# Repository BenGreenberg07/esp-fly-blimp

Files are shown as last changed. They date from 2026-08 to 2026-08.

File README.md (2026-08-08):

# ESP-FLY Autonomous Blimp

Converting a tiny ESP32-S3 quadcopter into an **autonomous helium blimp** that flies
itself to motion-capture waypoints — hand-flyable and self-flying from a live browser
panel, commanded over a custom **ESP-NOW** radio link so the laptop never has to leave
the lab Wi-Fi.

This repo contains the full stack: the drone firmware, the USB↔radio bridge firmware,
the real-time 3D control/tuning panels, and the printable gondola.

```
OptiTrack ──Wi-Fi──▶ Laptop ──USB──▶ XIAO ESP32-C6 ──ESP-NOW──▶ ESP32-S3 (blimp)
 (pose stream)      (control panel)   (radio bridge)            (guidance + mixing)
```

The laptop stays on the mocap network the whole time — control rides a **separate
ESP-NOW radio path**, solving the "one Wi-Fi radio can't be on two networks at once"
problem.

---

# Getting started

## 1. Getting the code

Clone it or download it — either works. You only need the files on your computer — there is nothing to install
globally and no build step for the ground station.

```bash
git clone https://github.com/BenGreenberg07/esp-fly-blimp.git
cd esp-fly-blimp
```

No git? Click the green **Code ▾ → Download ZIP** button on GitHub and unzip it. Same
thing.

## 2. Minimum files required

**To FLY (ground station only) — this is most people, most of the time:**

| You need | Why |
|---|---|
| `run.py` | the launcher you press ▶ on |
| `config.json` | your Motive IP + rigid-body ID — **you must edit this** |
| `requirements.txt` | the three Python packages |
| `control/` | the panel server + the browser pages + the saved tuning |
| `optitrack_natnet/` | the mocap client (includes a macOS multicast fix) |

That's it. You can ignore `esp-drone/`, `espnow_bridge/`, `hardware/`, `docs/`, and
`archive/` entirely unless you are building or reflashing a blimp.

**To BUILD or REFLASH a blimp**, you also need `esp-drone/` (drone firmware),
`espnow_bridge/` (bridge firmware), and `hardware/` (the printable gondola). See
**[Building a blimp from scratch](#building-a-blimp-from-scratch)** below.

## 3. Install and configure

```bash
pip install -r requirements.txt
```

Then edit **`config.json`**:

```json
{ "motive_ip": "192.168.0.4", "body_id": 531, "up": "Z" }
```

| field | meaning |
|---|---|
| `motive_ip` | IP of the OptiTrack/Motive PC streaming NatNet |
| `body_id` | the blimp's Rigid Body **Streaming ID** in Motive |
| `up` | up axis, `"Z"` or `"Y"` (also togglable live in the panel) |

## 4. Run it

Open the folder in VS Code → **Run and Debug** (▶ in the left bar) → pick a panel and
press the green ▶. Or from a terminal:

```bash
python run.py --mode auto
```

The panel opens in your browser. Press **ARM** to connect the USB bridge, then fly.

> **Have running before you press ARM:** the blimp powered on, the ESP32-C6 bridge
> plugged into your computer, and your computer on the same network as the Motive PC.

**Nothing here needs a reflash.** Every gain is a live slider; the drone runs its own
guidance and the panel just streams pose, commands, and tuning to it.

## 5. What each script does

There are two scripts in this repo. The first is the one used for flying:

| Script | When you use it |
|---|---|
| **`run.py`** | **Every time you fly.** Starts the ground station: a small local web server plus the browser page you actually click on. |
| **`flash.py`** | **Rarely.** Only to put new firmware on a board. Not needed to fly, and not needed to change any gain. |

The word "panel" just means that browser page — the thing with the live 3D view, the
buttons, and the sliders. `--mode` picks which page you get (`auto`, `manual`, `wander`,
`swing`); they're all served by the same program.

**The controller is separate from the panel, and it isn't running on your laptop.** The
control math — steering toward the target, holding altitude — lives in the drone's own
firmware (`blimp_guidance.c`). Your laptop only tells it *where it is* and *where to go*,
and passes along gain changes when you move a slider. That's why nothing needs reflashing
when you tune, and why the path drawn on screen is a picture of what the drone is doing
rather than the thing steering it.

(The one exception is the experimental `swing` mode, where the controller does run on the
laptop — explained in [Next steps](#next-steps--the-s-blimp-4-motor-airframe).)

---

# Returning to a point after a hand push

Push the blimp by hand and it curves back to the point it was assigned. This needs no
special mode — it is a direct consequence of the constant-cruise pursuit controller.

1. `python run.py --mode auto`, then **ARM**.
2. Click **⋯ Path** (the path mode button in the *Auto path shape* card).
3. **Click once** in the 2D view, on the spot you want it to live. That single click is
   the whole configuration — one waypoint.
4. Leave **Loop** on. Press **▶ GO**.

It climbs to the target altitude, flies to your point, and then keeps circling it at its
minimum turn radius. Push it across the room and the steering carrot is still that one
point, so it banks around and comes back on a curve. Release it and it re-converges.

**It orbits rather than parks.** The forward motors run at constant cruise and can't
reverse, so the craft cannot brake to a stop — expect a slow circle around the point,
not a hover on it. If you want it to genuinely stop, sit still, and wait to be pushed,
use the **wander** panel instead (`python run.py --mode wander`): it cuts cruise on
arrival so the blimp coasts to a halt and is safe to grab, flashes the LED, waits for
your push, then flies to the next point.

### Suggested improvement: replace the constant cruise

The clearest place to take this further is the constant-cruise assumption itself. The
controller currently holds forward power fixed and only steers, which is what makes it
smooth on loops — but it is also the reason it can only orbit a point instead of settling
on it.

Worth building and testing: **a speed controller that modulates forward thrust by distance
to the target**, so the craft eases off as it approaches and coasts to a near-stop on the
point rather than circling it. Some useful starting material is already here:

- The **wander** mode already does a simple version — an approach taper that rolls cruise
  off linearly over the last metre or two, plus a `fwdMaxN = 0` "park" state on arrival.
  Generalising that into the main auto mode is the obvious first experiment.
- `control/flight_logs/plant_final_*.json` is an identified model of the vehicle's
  dynamics, so a stopping distance can be predicted rather than guessed. The craft coasts
  a long way: forward drag has a time constant of roughly 5–7 seconds.

Two things to expect. Because the motors cannot reverse, the approach has to be planned
early — by the time it is close, cutting thrust is the only remaining control. And below
roughly 0.15 m/s the constant sideways drift becomes comparable to the forward speed, so
creeping in slowly tracks *worse*, not better. A decelerating approach that still arrives
with some speed is likely the practical target. The complete fix is hardware: H-bridge
drivers giving the motors reverse thrust, and therefore actual braking — see
[Future additions](#future-additions).

---

# The four panels

All of them are the same server (`control/panel_server.py`) started in a different mode.
See **[control/README.md](control/README.md)** for the full detail.

### ⭐ Auto — `python run.py --mode auto` (port 8601)
The day-to-day tool. Streams your live mocap pose to the drone's **on-board guidance**
(firmware `blimp_guidance.c`) — pure-pursuit steering with a lookahead carrot plus an
altitude PID. Fly a drawn **path**, a **circle**, or a manual X/Y **point**.
Every gain is a live slider. Also has hand-fly, gamepad control, sys-ID test buttons, and
per-run CSV/PNG logging.

### Manual — `python run.py --mode manual` (port 8611)
Pure hand-fly, no autonomy: `W/S` forward, `A/D` turn, `Q/E` up/down, `Space` = kill,
plus hover-assist, trim, and per-direction power sliders. The simplest option for a first
flight, a bridge check, or a motor sanity check.

**Gamepad supported** (Auto mode has it too). An Xbox controller — or any USB/Bluetooth
pad the browser recognises — gives you *proportional* control instead of on/off keys:
**RT** = forward throttle, **right stick X** = turn, **left stick Y** = up/down,
**B** = KILL. The keyboard keeps working alongside it, and if the pad is unplugged or the
tab loses focus the panel falls back to the keys within a fraction of a second, so a
forgotten pad can never hold the motors on. Browsers only expose a gamepad after you
press a button on it, so "no pad" until first input is expected.

### Wander — `python run.py --mode wander` (port 8613)
Flies to a point (random within a box, or a list you click), **parks and coasts to a
stop**, flashes the drone LED to say "safe to touch", waits for a hand push, then picks
the next point. The push is detected from mocap speed, so no extra sensor.

### Swing — `python run.py --mode swing` (port 8620) — **untested**
The new 4-motor S-blimp airframe with an SE(3) Mellinger controller. Built and
bench-verified but **never flown**. See [Next steps](#next-steps--the-s-blimp-4-motor-airframe).

---

# Building a blimp from scratch

My custom build guide video: [https://youtu.be/fltrr_Snbas](url)

Start to finish, in the order you should actually do it.

### Step 1 — Parts

| Part | Notes |
|---|---|
| Seeed **XIAO ESP32-S3** micro-drone (ESP-Drone) | the flight board — 4 brushed motor channels |
| A second **XIAO ESP32-S3** (or ESP32-C6) | the USB↔ESP-NOW bridge that plugs into your laptop |
| 4× brushed coreless motors + props | 2 forward, 1 up, 1 down (see the mixer below) |
| Helium envelope (mylar) | must lift the gondola + battery with a little margin |
| 1S LiPo | small — weight is everything |
| Printed gondola | `hardware/` — see step 2 |
| OptiTrack / Motive + markers | for anything autonomous |

### Step 2 — Print the gondola

In **`hardware/`**:

| File | What it is |
|---|---|
| `gondola-frame-v5.stl` | the flying gondola — print this one |
| `balloon-mount-v2.stl` | the pad that tapes to the envelope |
| `s-blimp-frame-test2.stl` | the 4-motor S-blimp frame (next-gen, see below) |
| `blimp-gondola-mount.f3d`, `esp-blimp-frame.f3d` | Fusion 360 sources, if you want to change dimensions |

**Two geometry choices that matter more than any gain:**
- **Spread the two forward motors as wide as you can.** Yaw torque scales with their
  separation, and turn authority is the single biggest limit on this vehicle.
- **Mount the gondola centred under the envelope.** An off-centre mount gives a constant
  sideways drift that no controller can remove — this was measured and confirmed, and it
  is the dominant tracking error at low speed.

### Step 3 — Wire the motors

Motor roles are set in firmware, not by which wire you solder where, so you can fix a
mistake in software. The default map (`power_distribution_stock.c`):

```
M1 = DOWN      M2 = forward-LEFT      M3 = forward-RIGHT      M4 = UP
```

Verify it before you fly: `python control/check_link.py --spin` spins each channel
briefly at low power (**props off**) so you can see which motor is which. If they don't
match, edit the `MOTOR_FWD_LEFT / MOTOR_FWD_RIGHT / MOTOR_UP / MOTOR_DOWN` defines and
reflash — don't resolder.

### Step 4 — Flash the drone (ESP32-S3)

Install **ESP-IDF v5.0.x**, then:

```bash
cd esp-drone
idf.py set-target esp32s3      # FIRST TIME ONLY — the committed sdkconfig needs this
idf.py build
idf.py -p /dev/cu.usbmodemXXXX flash
```

Or let the helper script do all of that for you, on any OS:

```bash
python flash.py drone
```

It finds the port, sets up ESP-IDF if it isn't already on your PATH, and builds and
flashes in one step.

> **If flashing fails** with *"No serial data received"* or *"Invalid head of packet"*:
> the S3 talks over its internal USB-Serial-JTAG. Add `--before usb_reset`, or unplug the
> LiPo and replug the USB cable, then retry immediately. The chip is never damaged by a
> failed connect — esptool fails before it writes anything.

### Step 5 — Flash the bridge (ESP32-S3 or C6)

The bridge can be **either a XIAO ESP32-S3 or a XIAO ESP32-C6** — the same sketch builds
for both (the C6-only antenna switch is compiled out on an S3). An S3 is the easy choice
since it's the same board as the drone:

```bash
python flash.py bridge            # XIAO ESP32-S3 (default)
python flash.py bridge --board c6 # XIAO ESP32-C6
```

Needs `arduino-cli` with the Arduino **esp32 core 3.x**. The Arduino IDE works too — open
`espnow_bridge/espnow_bridge.ino` and pick board `XIAO_ESP32S3` or `XIAO_ESP32C6`.

> If you use `arduino-cli` by hand, note that `upload` on its own re-flashes the *last
> compiled* binary — always `compile --upload` together or you'll flash a stale sketch.
> (`flash.py` does this correctly for you.)

> **Using a C6?** Check whether your board has a u.FL external-antenna connector. The
> sketch enables the external antenna, so the physical antenna must be attached — with
> the switch set and no antenna fitted, range is *worse* than stock.

Your USB adapter will usually only show **one** port at a time, so flash the two boards
one after the other, not together.

### Step 6 — Bind the drone to its bridge

There is **no MAC address to type in**. Pairing is a 4-byte tag called `FRAME_MAGIC` that
both ends stamp on every packet and reject if it's missing — that's what stops your blimp
from being flown by the other ESP-NOW traffic in the room (which was a real bug: foreign
frames were being parsed as gain updates and crashing the drone).

A bridge and a drone are **bound when their `FRAME_MAGIC` values match**:

| File | Where |
|---|---|
| `espnow_bridge/espnow_bridge.ino` | search for `FRAME_MAGIC` (~line 42) |
| `esp-drone/components/espnow_control/espnow_control.c` | search for `FRAME_MAGIC` (~line 46) |

Out of the box both are `{0xB1, 0x12, 0x9F, 0x5A}` and one drone works with no changes.

**Flying a second blimp in the same room:** give triplet #2 (its own laptop + bridge +
drone) a different `FRAME_MAGIC` — any 4 bytes — set **identically in both files**, then
reflash **both** of its boards. Leave triplet #1 and `TELEM_MAGIC` alone, and keep
everyone on channel 1. Full write-up: [espnow_bridge/README.md](espnow_bridge/README.md).

### Step 7 — First flight

1. Fill the envelope so it is **very slightly negatively buoyant** — it should sink
   slowly when you let go. Trim with tape.
2. Plug the C6 into the laptop, power the blimp.
3. `python control/check_link.py` — confirms the drone is actually replying over
   ESP-NOW (motor telemetry, not just an open serial port). Do this before blaming the
   panel.
4. `python run.py --mode manual` → **ARM** → hand-fly it. Get up/down and turning
   working, and set the power sliders where it feels controllable.
5. Only then go autonomous: `python run.py --mode auto`, create your rigid body in
   Motive, check the tracking pill goes green, and try the
   [come-back-when-pushed](#make-it-come-back-when-you-push-it) recipe above.

**If it turns the wrong way**, hit **⟳ Flip turn direction** in the panel (it flips the
sign of `turnMaxPwm`). Don't rewire.

---

# Tuning

Every gain — manual powers/trims and autonomous pursuit/hover gains — is a live slider.
Values ride the ESP-NOW link and update the controller in RAM instantly, with no reflash.
The panels are **self-contained** (pure-canvas 2D/3D, no CDNs) so they run on a
locked-down lab network, and they save automatically.

`control/mocap_config.json` ships with **the tuning currently flying on my blimp**, so a
fresh clone starts from known-good numbers instead of defaults:

| | |
|---|---|
| `fwdMaxN` 0.18 | constant forward cruise — the main speed/turn-radius trade |
| `kpHead` 2.65, `kdHead` 0.037 | pursuit steering PD (kd is the anti-overshoot term) |
| `turnCap` 0.9, `turnBoost` 0.35 | turn authority and how symmetric the differential is |
| `driftK` 1.3 | crab into the sideways drift |
| `zff` 19000, `vertMaxPwm` 28000 | buoyancy feedforward and its output ceiling |

**Radius scales with speed.** Flying wider circles than you drew is almost always
`fwdMaxN` being too high, not a steering gain. Slowing down is the strongest lever.

# Repo layout

```
run.py                  ▶ the launcher (VS Code ▶, or `python run.py --mode auto`)
config.json             your Motive IP + rigid-body IDs — EDIT THIS
requirements.txt        Python deps (numpy, matplotlib, pyserial)

control/                the ground station — everything you need to fly
  ├─ panel_server.py          the server behind all four modes
  ├─ auto_panel.html          Auto page (2D/3D mocap view, path drawing, live tuning)
  ├─ manual_panel.html        Manual hand-fly page
  ├─ wander_panel.html        Wander page (park → wait for a push → next point)
  ├─ swing_panel.html         Swing / S-blimp page (untested)
  ├─ swing_panel_server.py    Swing server — separate controller and motor layout
  ├─ mellinger_core.py        SE(3) Mellinger controller + the geometry-driven mixer
  ├─ swing_trajectory.py      trajectory generator for the swing build
  ├─ mocap_config.json        the tuning that is currently flying
  ├─ check_link.py            terminal-only link + motor test (run this first)
  └─ flight_logs/plant_final_*.json    identified dynamics model

hardware/               printable gondola (STL) + Fusion 360 sources + the S-blimp photo
esp-drone/              on-board drone firmware (ESP-IDF, ESP-Drone derivative)
espnow_bridge/          XIAO ESP32-C6 USB↔ESP-NOW bridge (Arduino) + pairing guide
optitrack_natnet/       OptiTrack NatNet client (incl. a macOS multicast fix)
docs/                   design notes and write-ups
archive/                earlier / superseded tools kept for history
```

Inherited the physical hardware rather than building your own? The specific IDs,
addresses, and quirks of the blimp I actually flew are in
[docs/THIS_EXACT_BLIMP.md](docs/THIS_EXACT_BLIMP.md).

### On-board firmware (custom components)
Built on Espressif's [ESP-Drone](https://github.com/espressif/esp-drone) (a Crazyflie
port). The custom work:
- `.../blimp_guidance.c` — the on-board guidance controller (pursuit + carrot + altitude
  PID + soft-start + spin abort)
- `.../power_distribution_stock.c` — blimp motor mixer (constant-forward + differential
  turn, vertical sign/dead-band) and the swing-build 4-motor branch
- `.../stabilizer.c`, `.../system.c` — blimp flight mode + radio-link selection
- `components/espnow_control/` — ESP-NOW receiver (manual + pose + gains frames, magic-tag
  filtering, link-loss failsafe) and the motor-telemetry return path
- `components/ble_control/` — BLE control link (parked)

---

# Next steps — the S-blimp 4-motor airframe

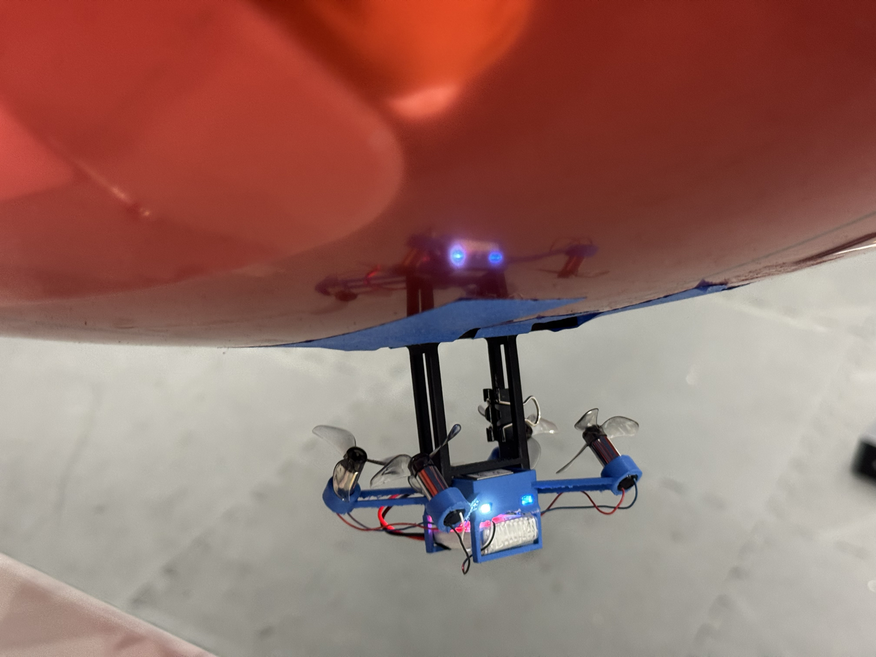
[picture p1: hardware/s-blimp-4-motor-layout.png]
The S-blimp gondola: four motors on an X-frame, canted ~45°


The next airframe replaces "2 forward + 1 up + 1 down" with **four motors on an X-frame,
all pointing roughly upward, canted about 45°** (photo above; frame is
`hardware/s-blimp-frame-test2.stl`).

**Motivation.** The current blimp's problems all trace back to one thing: the only
horizontal actuator is a pair of unidirectional forward motors, so it can't brake, can't
rotate in place, and drifts sideways through every turn. Four canted motors change the
actuation entirely — vertical thrust and yaw come out directly, and horizontal motion
comes from **tilting the envelope so the gondola's pendulum swings and the tilted lift
vector pulls it along** (hence "swing blimp").

**What already exists in this repo (built, bench-tested, `--mode swing`):**
- `control/mellinger_core.py` — a port of the Bitcraze **SE(3) Mellinger** controller,
  running host-side because it needs the full attitude quaternion every tick and the
  pose frame only carries position + yaw.
- A **geometry-driven mixer**: per-motor position + thrust axis → a 4×4 allocation
  matrix, solved by damped least-squares because the matrix is **singular by design**.
  Three switchable cant layouts (`lateral`, `foreaft`, `tangential`); unachievable force
  is routed into a moment, which is what makes the swing happen.
- Firmware support behind `#define BLIMP_SWING` (default 0 — nothing changes until you
  set it). In this build the drone is a **dumb 4-channel motor amplifier** and the wire
  format is the unchanged `0xA5` frame, so **only the drone reflashes, not the bridge**.
- A panel with props-off per-motor bench buttons and a motor-map editor, so you map
  channels to arms by clicking rather than resoldering.

**Remaining work:**
1. `python flash.py swing` (drone only; `python flash.py drone` puts the old blimp back).
2. Props off — bench-test M1..M4 and set the motor map from what actually spins.
3. Confirm the real cant matches a layout — watch which allocation row reads zero.
4. Raise `hover` until it floats, then ENGAGE with the target at its current position.
5. **Start the rate-D gains (`kw_*`, `kd_omega_rp`) well below the reference values** —
   they assume a 500 Hz IMU, but here body rates come from 25 Hz mocap.

---

# Future additions

### PCB with an integrated ESP32
Today the flight board is a XIAO module soldered onto a carrier — the between-board
joints are the most fragile thing on the vehicle and they add height and weight. The plan
is a **custom PCB with the ESP32-S3 native on the board**: no module, no inter-chip
soldering, one part to place.

### H-bridge motor drivers for reverse thrust
The single biggest limitation of the whole design is that the brushed motors are driven
by one low-side MOSFET each, so they only spin one way. Adding **H-bridge drivers
(e.g. DRV8833)** would let the forward motors reverse, which buys:
- **turning in place** — oppose the two forward motors instead of arcing
- **braking**, so it can actually stop on a point instead of orbiting it
- much tighter path tracking, since the min-turn-radius floor largely goes away

This needs signed PWM in the mixer and a firmware reflash once the hardware is wired.

**PCB design files and work-in-progress:**
[Google Drive folder](https://drive.google.com/drive/folders/18QSSe5u8A_p2iix2rqLfaRU-QODWJp0w)

---

# Wi-Fi mode (fallback, and how to revert)

ESP-NOW is the primary control link, but the drone **also brings up its own Wi-Fi access
point**, so Wi-Fi control is available at any time with no reflashing.

| Setting | Value |
|---|---|
| SSID | `ESP-DRONE_xxxxxxxxxxxx` |
| Password | `12345678` |
| Control link (CRTP over UDP) | `udp://192.168.43.42:2390` |

There's no bundled panel for this path — drive it with `cflib`'s `cfclient` or your own
script. Older keyboard-teleop clients (`drive_blimp*.py`) are in `archive/`.

**To make Wi-Fi the *only* radio**, edit
`esp-drone/components/core/crazyflie/modules/src/system.c`:

```c
#define ESPNOW_CONTROL_ENABLED 0   // 1 = ESP-NOW (default), 0 = Wi-Fi only
#define BLE_CONTROL_ENABLED    0   // (BLE link, normally off)
```

then rebuild and flash.

---

# Troubleshooting

**If the panel will not connect, or nothing moves,** run the terminal-only check first — it opens
the bridge, confirms the drone is really replying over ESP-NOW, and can spin each motor:

```bash
python control/check_link.py                       # test the link only (no spin)
python control/check_link.py --spin                # + spin each channel briefly, props OFF
python control/check_link.py --bridge-port COM5    # if auto-detect picks the wrong port
```

| Symptom | Cause |
|---|---|
| Tracking pill never goes green | laptop isn't on the mocap network, or the wrong `body_id` |
| Flies wider circles than drawn | `fwdMaxN` too high — slow it down |
| Turns the wrong way | **⟳ Flip turn direction** in the panel |
| Sinks during flight | buoyancy or battery sag, not gains — check `zff` isn't above `vertMaxPwm` |
| Random jitter / drone reboots ~3 s in | another ESP-NOW device in the room; check `FRAME_MAGIC` matches on both your boards |

---

# License
The `esp-drone/` firmware is a derivative of Espressif ESP-Drone and remains **GPL-3.0**
(original license headers retained). The host-side tools, panels, and hardware are
original work by the author.

---

*Built by Ben Greenberg. An exercise in re-purposing a flight controller, control design
around a hard actuation constraint, embedded radio links, and real-time tooling.*

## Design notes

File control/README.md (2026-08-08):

# control/ — the ground station

Everything that runs on your laptop. Start it from the repo root with
`python run.py --mode <auto|manual|wander|swing>`. Run these files directly only when
debugging.

## Contents

| File | What it does |
|---|---|
| `panel_server.py` | **The server.** Reads mocap (NatNet), streams pose + commands + gains to the drone over the USB↔ESP-NOW bridge, serves the browser page, and logs every run. One file, three pages. |
| `auto_panel.html` | The **Auto** page — 2D/3D mocap view, path drawing, live gain sliders, hand-fly, gamepad, sys-ID tests. |
| `manual_panel.html` | The **Manual** page — hand-fly only. |
| `wander_panel.html` | The **Wander** page — fly to a point, park, wait for a push, repeat. |
| `mocap_config.json` | Saved tuning (the numbers currently flying). Written automatically whenever you move a slider. |
| `check_link.py` | Terminal-only link + motor test. **Run this first** when something won't connect. |
| `flight_logs/` | Per-run `run_<timestamp>.csv` + plots. `plant_final_20260727.json` is the identified dynamics model and is kept in git. |

**Swing / S-blimp build (separate, untested):**

| File | What it does |
|---|---|
| `swing_panel_server.py` | Standalone server for the 4-motor airframe (port 8620). Own NatNet reader, own control thread. |
| `swing_panel.html` | Its page — per-motor bench buttons, motor-map editor, live allocation matrix. |
| `mellinger_core.py` | SE(3) Mellinger controller port + the geometry-driven damped-least-squares mixer. |
| `swing_trajectory.py` | Trajectory generator for that build. |

## Control flow

```
Motive ──NatNet──▶ panel_server.py ──USB serial──▶ C6 bridge ──ESP-NOW──▶ drone
```

Frames going down the wire are told apart by a 4-byte magic tag plus their length:

| Frame | Payload | Meaning |
|---|---|---|
| `0xA5` | 16 B | manual setpoint (roll/pitch/yaw/thrust) — also what the swing build reuses as 4 motor duties |
| `0xA6` | 32 B | mocap pose + goal — engages the drone's on-board guidance |
| `0xA7` | 84 B | the live gains — sent whenever you move a slider |
| `0xB7` | 16 B | **coming back:** motor telemetry (mL, mR, mUp, mDown), logged into every run CSV |

**The drone does the flying.** In auto mode the panel only supplies pose and tuning; the
pursuit + altitude loops run in firmware (`blimp_guidance.c`). That's why no gain change
ever needs a reflash, and why the path drawn on screen is a *mirror* of the on-board math
rather than the source of it.

## Safety behaviour

- **Browser watchdog** — if the page stops polling for 1.5 s the server stops streaming,
  and the drone's own stale-pose failsafe cuts the motors.
- **KILL** is always visible and always immediate.
- **Link-loss failsafe** — if the bridge goes silent the drone zeroes the motors within
  250 ms rather than flying away.
- **Soft-start** ramps the motors over ~0.7 s so engaging can't brown out the battery.

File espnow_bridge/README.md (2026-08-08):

# ESP-NOW bridge (XIAO ESP32-C6 or XIAO ESP32-S3)

USB↔ESP-NOW relay. The Mac talks to this board over USB serial; the board
rebroadcasts to the blimp over ESP-NOW. This keeps the Mac's Wi-Fi free for the
mocap (OptiTrack/NatNet) network — no router, no Wi-Fi join, no pairing UI.

**Same sketch, same file (`espnow_bridge.ino`), either board.** The bridge can
be a Seeed XIAO ESP32-**C6** or a Seeed XIAO ESP32-**S3** — pick whichever you
have. The only difference is which `arduino-cli --fqbn` you flash with (see
"Flashing" below); nothing in the sketch needs editing either way. (The one
board-specific bit, the C6's RF-antenna-switch pins, is already handled for
you at compile time via `#if defined(CONFIG_IDF_TARGET_ESP32C6)` — an S3
bridge just skips that block and uses its fixed onboard antenna.)

```
Mac (panel) --USB serial--> XIAO ESP32-C6 or -S3 --ESP-NOW--> ESP32-S3 (blimp)
            <--0xB7 telem-- (bridge relays)      <----------- (motor telemetry)
```

---

## "Where do I put the MAC address?"

**Nowhere — and that's deliberate. There is no MAC address to configure.**

The bridge **broadcasts** to `FF:FF:FF:FF:FF:FF`, so it does not need to know the
drone's MAC, and the drone does not need to know the bridge's:

```c
// espnow_bridge.ino
static uint8_t BCAST[6] = {0xFF, 0xFF, 0xFF, 0xFF, 0xFF, 0xFF};
```

If you flashed a *new* drone board, or swapped the C6 for another bridge, **you
do not have to change anything.** They will link up as long as the three things
below match.

> **Why broadcast instead of unicast?** An earlier version unicast to the drone's
> STA MAC. That broke once the drone started running ESP-NOW
> on top of its Wi-Fi SoftAP, because its *active* interface MAC became the **AP**
> MAC, not the STA MAC — so every send failed with `ESP_ERR_ESPNOW_IF (0x306c)`,
> silently (receive still worked, so it looked fine). Broadcast is delivered
> regardless of which interface is up, so it just works. Don't "fix" this back to
> unicast unless you have a reason.

---

## What actually pairs the two boards

Three things must match. If the link is dead, check them in this order.

### 1. Wi-Fi channel — must be the same on both

| Side | File | Setting |
|---|---|---|
| Bridge (C6 or S3) | `espnow_bridge/espnow_bridge.ino` | `static const uint8_t ESPNOW_CHANNEL = 1;` |
| Drone (S3) | `esp-drone/components/espnow_control/espnow_control.c` | pinned by the SoftAP, `WIFI_CH = 1` |

The drone runs ESP-NOW *on top of* its SoftAP, which pins the channel. (This also
fixed an old bug where `esp_wifi_set_channel()` wouldn't stick in pure-STA mode.)

### 2. `FRAME_MAGIC` — the real "pairing key"

This is what actually keeps *your* blimp listening to *your* bridge:

```c
// MUST be identical in BOTH files:
//   espnow_bridge/espnow_bridge.ino
//   esp-drone/components/espnow_control/espnow_control.c
static const uint8_t FRAME_MAGIC[4] = { 0xB1, 0x12, 0x9F, 0x5A };
```

Every frame the bridge broadcasts is prefixed with these 4 bytes. The drone
**rejects anything without them**.

This exists because a shared lab is full of *other* ESP-NOW traffic, and the
drone distinguishes frame types by **length**. Foreign frames were being parsed
as our gain/pose frames — garbage gains → NaN → crash ~3 s after power-up, and
garbage poses → the autonomous controller chasing junk. The magic tag fixed it.

**If you want two blimps flying in the same room at once, give each pair its own
`FRAME_MAGIC`** (change it in both that pair's files and reflash both). That is
the supported way to separate them — not MAC addresses. See
["Multiple drones in the same room"](#multiple-drones-in-the-same-room) below
for the full checklist.

### 3. `TELEM_MAGIC` — the return path

Same idea for telemetry coming *back* from the drone:

```c
static const uint8_t TELEM_MAGIC[4] = { 0xB7, 0x1E, 0x30, 0xA5 };
```

The bridge forwards those frames to the Mac over USB as `0xB7 + 16 bytes`
(4 × LE float32: `fwdL, fwdR, up, down`).

---

## Multiple drones in the same room

Each **Mac + bridge (C6 or S3) + drone (S3)** is one triplet. To fly a second blimp
alongside the first, build a second triplet with its own `FRAME_MAGIC` — not a
different MAC address (broadcast doesn't use MACs, see above) and not a
different Wi-Fi channel (leave both on channel 1; the magic tag is what keeps
them apart, and every extra channel is one more thing that has to match).

1. Pick a second 4-byte value, e.g. `{ 0xC2, 0x44, 0x1A, 0x7E }` — anything
   that isn't `{ 0xB1, 0x12, 0x9F, 0x5A }` (triplet 1) works.
2. Set it identically in **both** files for triplet 2, and reflash both boards:
   - `espnow_bridge/espnow_bridge.ino` → `FRAME_MAGIC[4]` (~line 42)
   - `esp-drone/components/espnow_control/espnow_control.c` → `FRAME_MAGIC[4]` (~line 46)
3. Leave `TELEM_MAGIC` alone unless you also need to tell the two triplets'
   *telemetry* apart on the same USB host — for two separate Macs (one bridge
   each) this doesn't matter.
4. Triplet 1's bridge/drone keep the original magic — don't touch those files.

With mismatched magics, each drone only accepts frames from its own bridge (and
ignores the other bridge's broadcasts as "foreign," same as it already ignores
other lab traffic) — so both blimps can be flown from separate Macs/panels in
the same room without cross-talk or reflashing anything each session.

---

## Frame formats (Mac → bridge → drone)

The bridge is a dumb relay: it reads a framed packet on USB serial and
rebroadcasts the payload with `FRAME_MAGIC` prepended. **The drone tells frame
types apart by payload LENGTH**, so these sizes matter:

| USB header | Payload | Meaning |
|---|---|---|
| `0xA5` | 16 B — 4 × float32 `roll, pitch, yaw, thrust` | manual setpoint |
| `0xA6` | 32 B — 8 × float32 `cx,cy,cz,cyaw, tx,ty,tz,tyaw` | mocap pose + goal |
| `0xA7` | 4 × N B — N × float32 gains | live gain update |

If you add or remove a gain, the `0xA7` length changes and **the drone, the
bridge, and the panel must all be updated together** or frames get misparsed.

---

## Flashing

The two boards use **different toolchains** — this trips people up:

```bash
# Bridge — Arduino, NOT idf.py. Same espnow_bridge.ino, board-specific --fqbn only:

# XIAO ESP32-C6 bridge:
arduino-cli compile --fqbn esp32:esp32:XIAO_ESP32C6 --upload -p /dev/cu.usbmodemXXXX espnow_bridge/espnow_bridge.ino

# XIAO ESP32-S3 bridge:
arduino-cli compile --fqbn esp32:esp32:XIAO_ESP32S3:CDCOnBoot=cdc --upload -p /dev/cu.usbmodemXXXX espnow_bridge/espnow_bridge.ino

# Drone (ESP32-S3) — ESP-IDF
cd esp-drone && idf.py -p /dev/cu.usbmodemXXXX flash
```

**S3 bridge gotcha:** the `CDCOnBoot=cdc` fqbn option (or, in the Arduino IDE,
Tools → **USB CDC On Boot → Enabled**) is required on S3 — without it, `Serial`
doesn't route over the native USB port and the Mac never sees the bridge as a
serial device at all. The C6 doesn't need this option (its default is already
correct). If `arduino-cli board list` doesn't show `XIAO_ESP32S3` as an option,
your installed "esp32 by Espressif" core is too old — update it.

**Gotcha (both boards):** `arduino-cli upload` on its own flashes the *last
compiled* binary — it does **not** recompile. After editing the `.ino`, always
use `compile --upload` or you will silently flash a stale sketch.

The USB adapter typically exposes only **one** `usbmodem` port at a time, so
flash the boards one at a time.

---

## Troubleshooting

| Symptom | Likely cause |
|---|---|
| Drone never responds | Channel mismatch, or `FRAME_MAGIC` differs between the two files |
| Bridge counts `rxAll` climbing but `rxTel` stays 0 | It's hearing other lab traffic, not your drone — check the drone is actually transmitting |
| Motors keep spinning after unplugging the bridge | Old sketch with the idle heartbeat — reflash the bridge (current version goes silent, so the drone's failsafe fires) |
| S3 bridge: no serial port shows up at all | `USB CDC On Boot` wasn't enabled at flash time — reflash with `CDCOnBoot=cdc` (or enable it in the IDE), see "Flashing" |
| Sends fail with `0x306c` | `ESP_ERR_ESPNOW_IF` — interface mismatch; make sure you're broadcasting, not unicasting to a stale MAC |
| Link works but nothing moves | Not a link problem — check ARM state and the panel's KILL/watchdog |

The bridge prints a status line with `rxAll` / `rxTel` counters; open the serial
monitor on the bridge board (C6 or S3) to see whether frames are moving at all.

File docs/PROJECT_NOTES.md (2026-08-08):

# Design notes

The rationale behind the design. The [README](../README.md) covers how to run the system;
this covers the reasoning, the protocol internals, and the findings that required
substantial flight testing to establish.

---

## 1. The architecture, and the problem it solves

```
OptiTrack ──Wi-Fi──▶ Laptop ──USB──▶ XIAO ESP32-C6 ──ESP-NOW──▶ ESP32-S3 (blimp)
```

The constraint that produced this shape: **a laptop has one Wi-Fi radio and can't be on
two networks at once.** The mocap stream arrives over the lab network; the drone
originally hosted its own access point. You could have one or the other, never both.

Three fixes were tried before this one:

- **Put the drone on the lab Wi-Fi.** Failed — the campus AP is MAC-locked and deauthed
  the drone (`reason=2, AUTH_EXPIRE`) forever. Not fixable in firmware.
- **BLE as a second link.** Failed. Wi-Fi AP + BLE running together browns out the
  board — two 2.4 GHz radios exceed the power budget and the chip reboot-loops. Even
  BLE-alone never held a connection. Parked; the code is still in `components/ble_control/`.
- **ESP-NOW instead.** Works. It's connectionless, shares the one Wi-Fi radio (no
  brownout), and needs no association — so the laptop stays on mocap and control rides a
  USB-attached C6 bridge.

One non-obvious trap: ESP-NOW must run **on top of** the existing Wi-Fi init, not instead
of it. Skipping `wifiInit()` broke the boot entirely — it also creates the base
netif/event-loop the rest of the firmware needs, so the flight loop never started.

## 2. The wire protocol

Frames carry a 4-byte magic tag and are dispatched on length:

| Direction | Frame | Payload | Meaning |
|---|---|---|---|
| → drone | `0xA5` | 16 B | manual setpoint (4 × float32) |
| → drone | `0xA6` | 32 B | mocap pose + goal (8 × float32) |
| → drone | `0xA7` | 84 B | the live gain set |
| ← laptop | `0xB7` | 16 B | motor telemetry (mL, mR, mUp, mDown) |

**Why the magic tag exists.** This was the most costly bug in the project. The
receiver originally told frame types apart **by length alone**. The lab is full of other
ESP-NOW devices, and their broadcasts happened to land in our length ranges: a foreign
103-byte frame was parsed as a gain update, wrote garbage gains, produced NaNs, and
panicked the drone about three seconds after power-up. Shorter foreign frames were parsed
as mocap poses, so the guidance chased phantom positions and jittered.

Every symptom seen that week — the ~3 s power-cycle, the jitter, "it flies to the wrong
place" — was that one bug. `FRAME_MAGIC` (a 4-byte prefix both ends must agree on) fixed
it and doubles as the pairing mechanism for flying several blimps in one room.

> This is also why the "open brownout issue" that used to be documented here is gone.
> It presented exactly like undervoltage — barely lifts, falls, power-cycles — but it was
> the foreign-frame crash. Battery sag is still worth checking first on any new symptom,
> but that specific fault was software.

**A second silent failure worth recording:** `esp_now_send`'s peer `ifidx` must match the
drone's actual Wi-Fi mode. Hard-coding `WIFI_IF_AP` while the drone ran in STA mode made
every send return `ESP_ERR_ESPNOW_IF` — while *receive* kept working fine, so the link
looked healthy and only the telemetry was missing. Query `esp_wifi_get_mode()` and pick
accordingly.

## 3. Where the control math runs, and why

**On the drone.** The laptop streams pose and gains; `blimp_guidance.c` does pursuit
steering, the altitude PID, soft-start, and the spin abort. Two reasons: the control loop
shouldn't depend on Wi-Fi latency, and it means **every gain is tunable live** over the
`0xA7` frame with no reflash — which is what made hundreds of tuning iterations practical.

The exception is the swing/S-blimp build, where the controller runs host-side because
Mellinger needs the full attitude quaternion every tick and the pose frame only carries
position plus yaw. Growing the frame would force a reflash of *both* boards on every
change, so there the drone is deliberately a dumb 4-channel amplifier.

## 4. What the vehicle can and can't do

The drivetrain is two unidirectional forward motors (steering is their difference), one
up and one down. Consequences, all confirmed in flight:

- **It cannot brake.** No reverse thrust, so it coasts. Arriving at a point means
  planning the approach, not stopping at it.
- **It cannot rotate in place.** Any turn command also pushes it forward — turning is an
  arc, always.
- **It drifts sideways through every turn.** Lateral velocity is generated by the turn
  itself (`v̇ ≈ −(1/ρ)·u·r`) and decays with a ~6 s time constant, so the drift outlives
  the corner that caused it.
- **Minimum flyable turn radius is about 1–1.25 m.** Below that, tracking collapses into
  loops. Paths are filleted so they never demand a tighter corner.
- **Turn radius scales with speed.** Flying wider circles than commanded is nearly always
  cruise being too high, not a steering gain.

## 5. Control approaches tried

| Approach | Outcome |
|---|---|
| Decoupled PID (altitude / heading / forward) | Works. Still the basis of what flies. |
| Rotate-first, then translate | Failed — fights a vehicle that can't rotate in place. |
| Pulse-and-brake yaw (bang-bang, from hand-flying) | Worked manually, too brittle automatically. |
| Pure pursuit with a lookahead carrot | **This is what's in use.** Constant cruise, steer at a point ahead, flow through corners instead of stopping at them. |
| Model-predictive control (MPPI, then IPOPT/CasADi) | Excellent in simulation, poor in the room. Removed. |
| Anticipatory curvature preview (slow before corners) | Helped in sim, not clearly in flight. Removed. |

**Why MPC was removed.** Both solvers beat pursuit convincingly against the identified
plant — and then tracked worse in the air. The honest reading is that the plant model was
fitted from limited flight data (the yaw channel in particular was never cleanly
identifiable), so the optimizer was solving the wrong problem very precisely. A controller
that assumes less was more robust to that error than one that assumes more.

**Why the drift cannot be cancelled.** To oppose sideways drift using only forward thrust,
you must crab at an angle where `sin(β) = drift / forward`. Measured mount drift is
~0.15 m/s and slow cruise is ~0.15 m/s, so that's a ~45° crab — marginal and unstable.
Model-based feedforward was tested and *lost* to simple reactive crabbing. The real fixes
are physical: centre the gondola under the envelope, spread the forward motors wider, or
add H-bridges so the motors can reverse.

## 6. Safety mechanisms

- **Soft-start** ramps motors over ~0.7 s. Engaging all channels at once from zero drew
  enough inrush to brown out the pack.
- **Stale-pose failsafe** — if pose frames stop for `staleMs`, the drone zeroes the
  motors and drops autonomy.
- **Link-loss failsafe** at the packet layer (~250 ms) catches the bridge being unplugged.
  An earlier idle "heartbeat" on the bridge actively defeated this and had to be removed:
  it kept the drone's timeout from ever firing, which is a flyaway waiting to happen.
- **Browser watchdog** — if the page stops polling for 1.5 s the server stops streaming.
- **Differentiate against the mocap sample timestamp, never wall-clock.** A duplicated or
  stale mocap sample divided by one loop tick produces a huge phantom velocity spike. That
  single bug degraded MPC tracking, and independently made the wander mode's push detector
  fire when nobody had touched the blimp.

## 7. Wi-Fi / CRTP fallback

The drone still brings up its own AP, and the ESP-Drone CRTP-over-UDP path still works
(`udp://192.168.43.42:2390`). Two things stock `cflib` gets wrong with this firmware:

1. The port must be explicit in the URI — `udp://<ip>:2390`, not `udp://<ip>`.
2. ESP-Drone appends a **trailing checksum byte** (`sum(bytes) & 0xFF`) to every UDP
   packet, which stock cflib neither adds on send nor strips on receive. Without patching
   that, the link connects and then silently drops every packet.

Both are handled in `archive/cf_udp_patch.py` if you ever go back to that path.

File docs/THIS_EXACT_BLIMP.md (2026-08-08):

# Picking up this exact blimp

Notes for whoever inherits **the physical blimp and bridge I left behind** — the specific
IDs, addresses, and settings that are already flashed and tuned, plus how to get it
flying again from a cold start.

> ### Which blimp this page is about
>
> This is the **original two-motor-forward blimp** — the one that actually flew, for
> months, and the one everything in this repo is tuned for:
>
> **2 forward motors + 1 up + 1 down.** It steers by running the two forward motors at
> different speeds, and holds altitude with the up/down pair.
>
> It is **not** the 4-motor "S-blimp" (all four motors pointing up, canted ~45°) that I
> was starting to build at the end. That's a different airframe with a different
> controller, it has **never been flown**, and nothing on this page applies to it. If you
> have both on the shelf, this page is the one with **two horizontal props on the front**.
>
> Everything below assumes the standard build. If the drone was left on the experimental
> firmware, `python flash.py drone` puts it back — see
> [step 0](#0--make-sure-its-on-the-right-firmware) below.

If you're building a *new* blimp, you want the main [README](../README.md) instead.

---

## What you should have

| Item | What it is |
|---|---|
| **The blimp** | XIAO ESP32-S3 flight board in a printed gondola, hanging under a mylar envelope. Four brushed motors in the standard layout: **2 facing forward** (side by side, canted up ~15°), **1 facing up**, **1 facing down**. |
| **The bridge** | The one I used is a XIAO **ESP32-C6** on a short USB cable. **It has a u.FL external antenna — keep it attached.** The firmware drives the antenna switch high, so running it without the antenna is *worse* than a stock board, not neutral. (If you build a replacement, an ESP32-S3 works too — `python flash.py bridge`.) |
| **A 1S LiPo** | Charge it. A tired battery is the single most common cause of "it flies badly today" — see the altitude note below. |

Both boards are already flashed and already paired. **You should not need to flash
anything to fly.**

---

## The numbers

### Motion capture (OptiTrack / Motive)

| Setting | Value |
|---|---|
| Motive PC IP | `192.168.0.4` |
| Blimp rigid-body Streaming ID | **531** |
| Up axis | **Z** (Motive is Z-up here) |
| Typical stream rate | ~200 Hz |

These are exactly what's in `config.json` at the repo root, so a fresh clone is already
pointed at the right place. If Motive got reinstalled or the rigid body was rebuilt, the
Streaming ID is the thing that changes — check it in Motive and update `config.json`.

**Your laptop must be on the mocap network** for the pose stream to arrive. Control does
*not* use that network (it goes over ESP-NOW), so this is the only reason to be on it.

### Radio

| Setting | Value |
|---|---|
| ESP-NOW channel | **1** (both boards) |
| `FRAME_MAGIC` (laptop → drone pairing tag) | `{0xB1, 0x12, 0x9F, 0x5A}` |
| `TELEM_MAGIC` (drone → laptop telemetry) | `{0xB7, 0x1E, 0x30, 0xA5}` |
| Drone STA MAC | `80:B5:4E:F1:10:30` |
| Bridge base MAC | `f0:f5:bd:2d:0c:d8` |

There's no MAC to configure anywhere — the bridge broadcasts, and the two boards accept
each other because their `FRAME_MAGIC` matches. The MACs are listed only so you can
identify the boards if you have several.

> The magic tag isn't decoration. The lab is full of other ESP-NOW traffic, and before
> this filter existed foreign packets were being parsed as gain updates and crashing the
> drone a few seconds after power-up. If you ever see unexplained reboots or jitter,
> suspect a second transmitter before you suspect the tuning.

### Wi-Fi (fallback only)

The drone also brings up its own access point, which you don't need for normal flying:
SSID `ESP-DRONE_80B54EF11031`, password `12345678`, CRTP at `udp://192.168.43.42:2390`.

### How this blimp flies

It is not a quadcopter and does not behave like one:

- **Turning is differential.** There is no yaw thruster — it turns by running one forward
  motor harder than the other. So **every turn also pushes it forward**; it cannot spin
  on the spot.
- **It cannot brake.** The brushed motors only spin one direction, so it coasts. It
  arrives at a point by curving onto it, not by stopping on it.
- **Altitude is a separate pair** (the up and down motors) and is handled by its own PID,
  independent of everything else.
- **It's pendulum-stable.** The gondola hangs low, so it self-rights. There is no
  attitude/tilt loop to tune — don't go looking for one.

Minimum turn radius is about **1–1.25 m**, and radius grows with speed. This is the most
important characteristic to keep in mind when flying it.

### Motors

Channel → role, as flashed:

```
M1 = DOWN      M2 = forward-LEFT      M3 = forward-RIGHT      M4 = UP
```

**Verify this before trusting it** — see the open issue at the bottom of this page.

### Tuning

`control/mocap_config.json` holds the tuning that was actually flying, under the profile
named **`tilted`** (the forward props on this airframe are canted up ~15°, so forward
thrust also lifts a little — that's what the profile name means).

The values that matter most:

| Gain | Value | What it does |
|---|---|---|
| `fwdMaxN` | 0.18 | constant forward cruise. **The main lever.** Raise = faster but wider turns |
| `kpHead` / `kdHead` | 2.65 / 0.037 | pursuit steering PD; `kd` is what stops it overshooting the heading |
| `turnCap` / `turnBoost` | 0.9 / 0.35 | turn authority, and how symmetric the differential is |
| `driftK` | 1.3 | crabs the nose into the sideways drift |
| `zff` / `vertMaxPwm` | 19000 / 28000 | buoyancy feedforward and its ceiling |
| `turnMaxPwm` | **−32767** | **negative on purpose.** This board's turn direction is flipped; the sign is what corrects it |

If it ever turns the wrong way, don't rewire — press **⟳ Flip turn direction** in the
panel, which just flips that sign back.

---

## Cold-start procedure

### 0 — Confirm the firmware build

If the hardware has not been modified since I left it, this step can be skipped — both
boards are already flashed and paired. If you are unsure, or if the 4-motor build was
flashed onto it, restore the standard build before anything else:

```bash
python flash.py drone
```

That forces the `BLIMP_SWING` flag off and restores the normal two-forward-motor mixer
and the on-board guidance. It is always safe to run.

### Startup sequence

1. **Charge the LiPo.**
2. **Check the helium.** The envelope loses lift over days. It should be *very slightly*
   heavy — sinking slowly when released. Too light is much harder to fly than too heavy.
   Trim with tape.
3. **Plug the bridge into your laptop** (antenna attached), and **power the blimp**.
4. **Join the mocap network** and confirm Motive is streaming, with the blimp's rigid
   body present and tracking.
5. **Prove the radio link before opening any panel:**
   ```bash
   python control/check_link.py
   ```
   This opens the bridge and waits for the drone's own telemetry frames. It passing means
   the whole chain works. If it fails, nothing in the browser is going to help you.
6. **Hand-fly it first:**
   ```bash
   python run.py --mode manual
   ```
   ARM, then W/S forward, A/D turn, Q/E up/down, Space to kill. Confirm up/down goes the
   right way and turning feels like a turn.
7. **Then go autonomous:**
   ```bash
   python run.py --mode auto
   ```
   ARM, check the tracking pill is green, and try the come-back-when-pushed setup from
   the main README (Path mode, one waypoint, GO).

---

## Practical notes and known pitfalls

**Flashing the S3 fails a lot, and it's never broken.** If `idf.py flash` says *"No
serial data received"* or *"Invalid head of packet"*, use `--before usb_reset`, or unplug
the LiPo and replug the USB cable and retry immediately. esptool fails before it writes,
so a failed flash never damages what's already on the board. The BOOT/RESET buttons are
unreachable once the gondola is assembled, which is why this matters.

**The USB adapter shows one port at a time.** Flash the drone and the bridge one after
the other, not together. The port name flips between `usbmodem101` and `usbmodem1101` on
re-enumeration — that's normal.

**`arduino-cli upload` alone flashes a stale binary.** Always `compile --upload` together
when changing the bridge sketch. This cost me a whole lab session once: the bridge was
silently still running the previous sketch and nothing downstream made sense.

**If it sinks through the flight**, check the battery under load and the helium before
touching gains. There was a real bug once where `zff` had drifted above `vertMaxPwm`, so
the altitude PID's corrections were being clipped away entirely — that's fixed in the
committed config, but it's worth knowing the failure mode: the vertical motor pinned near
max the whole flight while the craft still sank.

**Wider circles than you drew is a speed problem**, not a steering-gain problem. Turn
radius scales with cruise speed. Lower `fwdMaxN` first.

**Don't fly two blimps on the same `FRAME_MAGIC`.** Give the second triplet its own
4-byte value in both `espnow_bridge.ino` and `espnow_control.c`, and reflash both of its
boards.

---

## Known open issue — verify the motor map

The last time I bench-tested motor channels, **pressing the M3 test button appeared to
drive both forward motors**, and M4 (up) didn't spin during a flight test even though it
spun when the battery was first connected — which means the motor itself is fine and the
problem is upstream of the motor.

I never fully closed this out. It's most likely a channel-mapping mismatch rather than
damaged hardware, so **before you trust the map above, verify it empirically**:

```bash
python control/check_link.py --spin      # PROPS OFF
```

This spins each channel briefly at low power. Watch which physical motor moves for each
channel, and if it disagrees with `M1=DOWN, M2=fwd-LEFT, M3=fwd-RIGHT, M4=UP`, fix it in
firmware by editing the `MOTOR_FWD_LEFT / MOTOR_FWD_RIGHT / MOTOR_UP / MOTOR_DOWN`
defines in `power_distribution_stock.c` and reflashing. **Don't resolder** — the mapping
is deliberately a software choice so wiring mistakes stay cheap.

---

## Reflashing

| Command | What it gives you |
|---|---|
| `python flash.py drone` | the standard 2-forward-motor blimp firmware — **this is the one you want, and it's what this blimp should always be running** |
| `python flash.py bridge --board c6` | reflashes **this** C6 radio bridge (use `--board s3` for an S3 one) |
| `python flash.py swing` | switches the drone to the experimental 4-motor S-blimp build. **Do not run this on this vehicle** — the mixer sends motor commands that assume four upward motors, so a 2-forward airframe will not fly. Recover with `python flash.py drone`. |

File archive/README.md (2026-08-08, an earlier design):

# `archive/` — earlier & superseded tools

These are kept for project history. **They are not the active flight path** — for that,
use the panels in [`control/`](../control/). Everything here predates the current
Mac-side pure-pursuit controller and the frame-profile manual panel.

## Blimp tools (superseded by `control/`)
| File | What it was |
|---|---|
| `drive_blimp.py` | first keyboard teleop (Wi-Fi/CRTP): WASD+QE, forward-ramp, anti-spin down-coupling |
| `drive_blimp_espnow.py` | keyboard teleop over the C6 ESP-NOW bridge |
| `drive_blimp_ble.py` | keyboard teleop over the (parked) BLE link |
| `fly_blimp.py` | IMU yaw-hold flyer + live param tuner |
| `blimp_mocap.py` | first autonomous mocap guidance (turn-to-face + drive-to-target), on-board-PID path |
| `blimp_control.py` | early per-motor channel test / demo / teleop |
| `motor_test.py` | per-motor channel spin test to identify wiring |
| `panel.html` | the original browser panel (pre-`control/` split) |

## Quadcopter tools (before the blimp conversion)
| File | What it was |
|---|---|
| `quad_fly.py`, `auto_flight.py`, `control_server.py`, `connect_test.py`, `flight_config.py` | stock-quad flight, autonomy, web control, link test, and config from the original ESP-Drone quadcopter build |

## Launchers
The `*.command` files are the macOS double-click launchers that paired with the tools
above (`FLY_BLIMP`, `DRIVE_BLIMP`, `MOCAP`, `TEST_BLIMP_MOTORS`, and the numbered quad
launchers `1_`–`4_`).

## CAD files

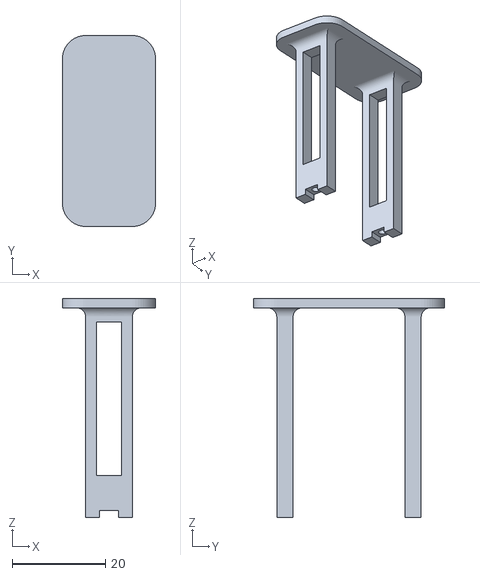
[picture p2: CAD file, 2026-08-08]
hardware/balloon-mount-v2.stl
20.0 x 41.0 x 47.0

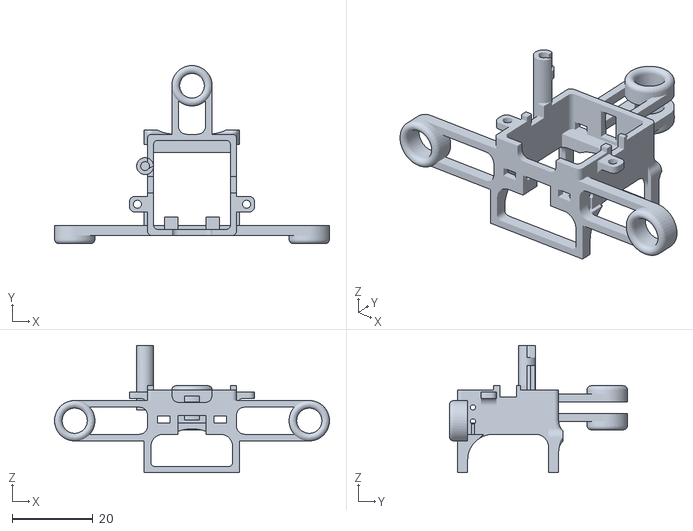
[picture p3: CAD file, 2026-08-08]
hardware/gondola-frame-v5.stl
68.0 x 44.0 x 31.5

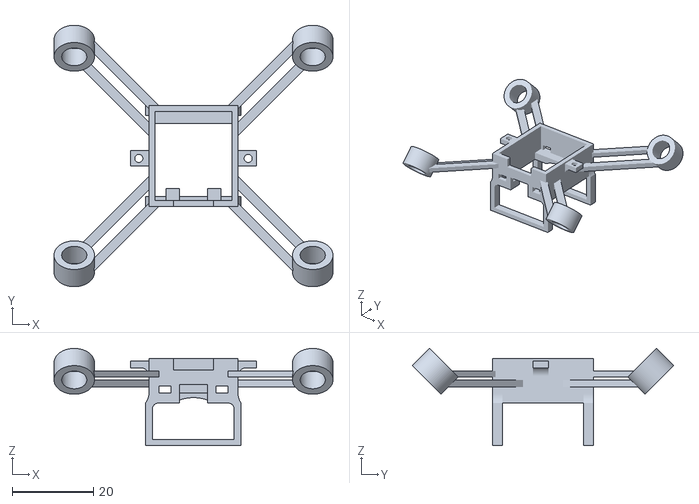
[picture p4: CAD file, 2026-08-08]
hardware/s-blimp-frame-test2.stl
68.9 x 64.5 x 24.0

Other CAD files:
hardware/blimp-gondola-mount.f3d
hardware/esp-blimp-frame.f3d

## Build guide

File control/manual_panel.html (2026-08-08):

—

# 🕹️ Blimp Manual Panel

Pure hand-flying, no autonomy. Keyboard or gamepad. Keyboard: W/S forward, A/D turn, Q/E up/down, Space = KILL.

Blimp trackingno data

NatNet0 Hz

ESP-NOW bridge—

▶ ARM (connect bridge) ■ KILL

Teleopfwd 0%

W fwdS brake A ↺D ↻ Q ↑E ↓

⊙ Hover: off

Hover holds a baseline Up thrust so it floats while you hand-fly (tune with the Up slider below).

🎮 Gamepadno pad

Xbox / any USB or Bluetooth gamepad works — proportional, unlike the on/off keys. RT = forward throttle (half-squeeze = half power), right stick X = turn, left stick Y = up/down, B = KILL. The keys keep working; the pad simply takes over while it is being used. Browsers only reveal a gamepad after you press a button on it, so "no pad" until first input is normal.

Turn trim0.00

Forward—

Up—

Down—

Left turn—

Right turn—

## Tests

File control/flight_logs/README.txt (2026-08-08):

# Flight logs are written here at runtime (run_*.csv, mpc_*.csv/png, latency_*.json).
# The identified plant model plant_final_20260727.json is required by the MPC.

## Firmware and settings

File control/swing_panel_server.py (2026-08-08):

#!/usr/bin/env python3
"""swing_panel_server.py -- standalone test rig for the SWING BLIMP Mellinger controller.

SEPARATE FROM EVERYTHING ELSE. This does not import, modify, or share state with
panel_server.py or any of the decoupled-blimp panels -- the proven decoupled
stack keeps working exactly as it does today. Run one panel at a time, though: they
all want the same C6 USB bridge.

    Motive --NatNet--> this Mac --mellinger_core--> USB --> C6 --ESP-NOW--> drone

The drone runs NO guidance here. It is a dumb 4-channel motor amplifier: the swing
firmware mixer takes the four values in the existing 0xA5 frame and writes them
straight to M1..M4. All the control math and all the airframe geometry live on this
side, so the cant angle / layout / gains are live-tunable with no reflash.

FRAME (unchanged length, so the C6 bridge needs NO reflash):
    0xA5 + 4 LE float32 = (M1, M2, M3, M4) motor duties, 0..32767 half-scale.
    The firmware doubles them because control_t's roll/pitch/yaw fields are int16.

Run it via FLY_SWING_MELLINGER.command.
"""
import argparse, glob, json, math, os, struct, sys, threading, time, webbrowser
from http.server import BaseHTTPRequestHandler, ThreadingHTTPServer

import mellinger_core as mel

DIR = os.path.dirname(os.path.abspath(__file__))
PORT = 8620                  # deliberately clear of 8601/8602/8603/8610/8421
TICK = 0.04                  # 25 Hz control + stream rate
HALF = 32767.0               # int16 half-scale the firmware doubles back up
CFG = os.path.join(DIR, "swing_config.json")

lock = threading.RLock()
RUNNING = True

S = {
    "raw": {"x": 0.0, "y": 0.0, "z": 0.0, "q": [0, 0, 0, 1], "valid": False, "t": 0.0},
    "frames": 0, "rate": 0,
    "up_axis": "Z",
    "armed": False,            # bridge open + streaming
    "engaged": False,          # Mellinger controller driving the motors
    "bridge": "", "err": "",
    "last_client": 0.0,
    "target": {"x": 0.0, "y": 0.0, "z": 1.0, "yaw": 0.0},
    "gains": dict(mel.MEL_DEFAULTS),
    "mix": dict(mel.MIX_DEFAULTS),
    "layout": "lateral",
    "motor_enable": [1, 1, 1, 1],
    # motor_map[arm position] = firmware channel (0..3 = m1..m4). Arm positions
    # are ordered front-right, rear-right, rear-left, front-left. Set it from the
    # panel after the props-off bench test tells you which channel is which.
    "motor_map": [0, 1, 2, 3],
    # What we SENT (fx, fy, mz, fz). The per-motor duties now live only on the
    # drone, and come back via "telem".
    "wrench": [0.0, 0.0, 0.0, 0.0],
    "ctl": {}, "log": {}, "mixinfo": {},
    "alloc": [], "auth": [0.0, 0.0],
    "vel": [0.0, 0.0, 0.0],
    "gyro": [0.0, 0.0, 0.0],
    "bench": None,             # (motor_index, duty) manual per-motor bench test
    # What the DRONE says it actually commanded to m1..m4 (0..65535 PWM), read
    # back over ESP-NOW. Compare against "duty" to tell a control-side problem
    # (never commanded) apart from a hardware one (commanded, did not spin).
    "telem": [0.0, 0.0, 0.0, 0.0],
    "telem_age": 999.0,
}


def _clamp(v, lo, hi): return lo if v < lo else (hi if v > hi else v)


def _wrap_pi(a):
    while a > math.pi:  a -= 2 * math.pi
    while a < -math.pi: a += 2 * math.pi
    return a


# ------------------------------------------------------------------ config --
def load_cfg():
    try:
        with open(CFG) as f:
            d = json.load(f)
    except Exception:
        return
    with lock:
        for k, v in (d.get("gains") or {}).items():
            if k in mel.MEL_DEFAULTS: S["gains"][k] = float(v)
        for k, v in (d.get("mix") or {}).items():
            if k in mel.MIX_DEFAULTS: S["mix"][k] = float(v)
        if d.get("layout") in mel.CANT_LAYOUTS: S["layout"] = d["layout"]
        if isinstance(d.get("target"), dict): S["target"].update(d["target"])
        if isinstance(d.get("motor_enable"), list) and len(d["motor_enable"]) == 4:
            S["motor_enable"] = [1 if v else 0 for v in d["motor_enable"]]
        mm = d.get("motor_map")
        if isinstance(mm, list) and sorted(mm) == [0, 1, 2, 3]:
            S["motor_map"] = [int(v) for v in mm]


def save_cfg():
    with lock:
        d = {"gains": dict(S["gains"]), "mix": dict(S["mix"]), "layout": S["layout"],
             "target": dict(S["target"]), "motor_enable": list(S["motor_enable"]),
             "motor_map": list(S["motor_map"])}
    try:
        with open(CFG, "w") as f:
            json.dump(d, f, indent=1)
    except Exception as e:
        with lock: S["err"] = "save failed: %s" % e


# ------------------------------------------------------------------ mocap ---
def _map_raw(r, up):
    x, y, z = r["x"], r["y"], r["z"]
    return (x, z, y) if up == "Y" else (x, y, z)


def _map_quat(q, up):
    """Motive quaternion -> our z-up control frame. For a Y-up stream the y and z
    axes swap, which for a quaternion means swapping those two components too."""
    qx, qy, qz, qw = q[0], q[1], q[2], q[3]
    return (qx, qz, qy, qw) if up == "Y" else (qx, qy, qz, qw)


def pose():
    """(pos xyz, quat xyzw, valid, sample_time) in the control frame."""
    with lock:
        r = dict(S["raw"]); up = S["up_axis"]
    p = _map_raw(r, up)
    q = mel.qnormalize(_map_quat(r.get("q", [0, 0, 0, 1]), up))
    return p, q, r.get("valid", False), r.get("t", 0.0)


def natnet_thread(server_ip, body_id, local_ip, multicast):
    sys.path.insert(0, os.path.join(DIR, "..", "optitrack_natnet"))
    try:
        from NatNetClient import NatNetClient
    except Exception as e:
        with lock: S["err"] = "NatNet import failed: %s" % e
        return

    def rb(idn, pos, rot):
        if idn == body_id:
            with lock:
                S["raw"].update(x=pos[0], y=pos[1], z=pos[2], q=list(rot),
                                valid=True, t=time.time())
                S["frames"] += 1

    try:
        c = NatNetClient()
        c.set_server_address(server_ip)
        if local_ip:
            c.set_client_address(local_ip)
        c.set_use_multicast(multicast)
        c.rigid_body_listener = rb
        c.run()
    except Exception as e:
        with lock: S["err"] = "NatNet run failed: %s" % e
        return
    last = 0
    while RUNNING:
        time.sleep(1.0)
        with lock:
            S["rate"] = S["frames"] - last
            last = S["frames"]
            if S["raw"]["valid"] and (time.time() - S["raw"]["t"]) > 1.0:
                S["raw"]["valid"] = False


# ----------------------------------------------------------------- bridge ---
def find_bridge_port():
    """Auto-detect the XIAO C6 bridge serial port."""
    try:
        from serial.tools import list_ports
        for p in list_ports.comports():
            blob = ("%s %s %s" % (p.device, p.description or "", p.manufacturer or "")).lower()
            if any(s in blob for s in ("usbmodem", "wchusbserial", "cp210", "esp", "xiao")):
                return p.device
    except Exception:
        pass
    g = (glob.glob("/dev/cu.usbmodem*") + glob.glob("/dev/cu.wchusbserial*") +
         glob.glob("/dev/ttyUSB*") + glob.glob("/dev/ttyACM*"))
    return g[0] if g else None


TELEM_MAGIC = b"\xB7\x1E\x30\xA5"
_telem_buf = bytearray()


def _read_telem(ser):
    """Drain the bridge serial and parse TELEM_MAGIC + 4 LE float32 motor commands.

    The bridge also prints ASCII status lines on this port; the magic is non-ASCII,
    so scanning for it can't collide with those."""
    global _telem_buf
    try:
        n = ser.in_waiting
        if n:
            _telem_buf += ser.read(n)
    except Exception:
        return
    if len(_telem_buf) > 4096:
        del _telem_buf[:-4096]
    while True:
        i = _telem_buf.find(TELEM_MAGIC)
        if i < 0 or len(_telem_buf) < i + 4 + 16:
            if i > 0:
                del _telem_buf[:i]
            return
        vals = struct.unpack("<ffff", bytes(_telem_buf[i + 4:i + 20]))
        del _telem_buf[:i + 20]
        with lock:
            S["telem"] = [round(v, 1) for v in vals]
            S["telem_age"] = 0.0
            S["_telem_t"] = time.time()


def wrench_frame(fx, fy, mz, fz):
    """0xA5 + 4 LE float32 = (F_x, F_y, M_z, F_z), i.e. the Mellinger controller's
    control_t fields (roll, pitch, yaw, thrust) sent straight through.

    The DRONE mixes these with the real Sblimp mixer -- see blimp_swing.h. Nothing is
    pre-mixed here, so what the controller computes is what the airframe gets.

    The ranges match what the firmware's ESP-NOW validator accepts (|pitch|,|yaw| <=
    40000; thrust in -1..70000); the controller already clamps F_x/F_y/M_z to
    +/-16000, and these caps are only a backstop against a NaN or a bad gain."""
    return b"\xA5" + struct.pack("<ffff",
                                 _clamp(float(fx), -16000.0, 16000.0),
                                 _clamp(float(fy), -16000.0, 16000.0),
                                 _clamp(float(mz), -16000.0, 16000.0),
                                 _clamp(float(fz), 0.0, 65535.0))


ZERO_FRAME = b"\xA5" + struct.pack("<ffff", 0.0, 0.0, 0.0, 0.0)


# ------------------------------------------------------- the control thread --
class _Vel:
    """Finite-difference world velocity + body rates from the mocap stream.

    Differentiates against each SAMPLE'S OWN timestamp, never wall-clock: if a
    sample is late, wall-clock dt makes the next fresh one look like a velocity
    spike, and the Mellinger D-terms carry gains in the tens of thousands on
    exactly that signal.
    """

    def __init__(self, a=0.45):
        self.a = a
        self.reset()

    def reset(self):
        self.prev = None
        self.v = [0.0, 0.0, 0.0]
        self.w = [0.0, 0.0, 0.0]

    def update(self, t, p, q):
        rpy = mel.quat2rpy(q)
        if self.prev is None or t <= self.prev[0] + 1e-6:
            if self.prev is None:
                self.prev = (t, p, rpy)
            return self.v, self.w
        dt = t - self.prev[0]
        pv, prpy = self.prev[1], self.prev[2]
        raw_v = [(p[i] - pv[i]) / dt for i in range(3)]
        raw_w = [_wrap_pi(rpy[i] - prpy[i]) / dt for i in range(3)]
        if max(abs(x) for x in raw_v) <= 5.0:              # reject glitch spikes
            self.v = [(1 - self.a) * self.v[i] + self.a * raw_v[i] for i in range(3)]
        if max(abs(x) for x in raw_w) <= 30.0:
            self.w = [(1 - self.a) * self.w[i] + self.a * raw_w[i] for i in range(3)]
        self.prev = (t, p, rpy)
        return self.v, self.w


def control_thread(bridge_port):
    ser = None
    ctrl = mel.MellingerController()
    mixer = mel.SwingMixer()
    vel = _Vel()
    was_engaged = False

    while RUNNING:
        with lock:
            armed = S["armed"]
        if armed and ser is None:
            try:
                import serial
                port = bridge_port or find_bridge_port()
                if not port:
                    raise RuntimeError("no C6 bridge serial port (plug in the XIAO C6)")
                ser = serial.Serial(port, 115200, timeout=0.1)
                time.sleep(0.3)
                with lock: S["bridge"] = port; S["err"] = ""
            except Exception as e:
                with lock: S["err"] = "bridge: %s" % e; S["armed"] = False
                time.sleep(0.4); continue
        if (not armed) and ser is not None:
            try:
                for _ in range(3):
                    ser.write(ZERO_FRAME); time.sleep(0.01)
                ser.close()
            except Exception:
                pass
            ser = None
            with lock: S["bridge"] = ""; S["wrench"] = [0.0] * 4
        if not (armed and ser is not None):
            time.sleep(0.05)
            was_engaged = False
            continue

        # WATCHDOG: panel gone (tab closed / laptop asleep) -> stop streaming, and
        # the drone's own ESP-NOW link-loss failsafe zeroes the motors.
        with lock:
            gone = (time.time() - S["last_client"]) > 1.5
        if gone:
            with lock:
                S["armed"] = False; S["engaged"] = False
                S["err"] = "client disconnected -> stopped"
            continue

        with lock:
            engaged = S["engaged"]; bench = S["bench"]
            tgt = dict(S["target"])
            gains = dict(S["gains"]); mixp = dict(S["mix"])
            layout = S["layout"]; men = tuple(S["motor_enable"])
            mmap = tuple(S["motor_map"])
        ctrl.set_gains(gains)
        mixer.set_params(dict(mixp, layout=layout))
        mixer.motor_enable = men
        mixer.set_motor_map(mmap)
        with lock:
            S["alloc"] = [[round(v, 4) for v in row] for row in mixer.A]
            S["auth"] = [round(mixer.auth_x, 3), round(mixer.auth_y, 3)]

        try:
            _read_telem(ser)          # drone -> host: what it actually commanded
            with lock:
                S["telem_age"] = round(time.time() - S.get("_telem_t", 0.0), 1)
            if bench is not None:
                # BENCH TEST, PROPS OFF. With the real Sblimp mixer every motor
                # carries the collective thrust, so a single motor CANNOT be driven
                # alone -- instead this sweeps one axis at a time:
                #   axis 0 = collective thrust  -> all four spin equally
                #   axis 1 = F_x, 2 = F_y, 3 = M_z -> differential on top of thrust
                # Axis 0 is the M4 test: if a motor stays still while the other three
                # spin at equal commanded thrust, that motor is not being driven.
                axis, mag = bench
                w = [0.0, 0.0, 0.0, 0.0]        # fx, fy, mz, fz
                base = _clamp(mag, 0.0, 0.5) * 65535.0
                if axis == 0:
                    w[3] = base
                elif 1 <= axis <= 3:
                    w[3] = base
                    w[axis - 1] = 0.35 * base   # differential kept well under thrust
                ser.write(wrench_frame(w[0], w[1], w[2], w[3]))
                with lock: S["wrench"] = [round(x, 1) for x in w]
                was_engaged = False

            elif engaged:
                p, q, valid, t = pose()
                if not valid:
                    ser.write(ZERO_FRAME)
                    vel.reset(); ctrl.reset()
                    with lock:
                        S["wrench"] = [0.0] * 4; S["err"] = "no mocap -> motors off"
                    time.sleep(TICK); continue
                if not was_engaged:
                    ctrl.reset(); vel.reset()
                    was_engaged = True
                v, w = vel.update(t, p, q)
                rpy = mel.quat2rpy(q)

                setpoint = {
                    "mode": {"x": "abs", "y": "abs", "z": "abs", "yaw": "abs"},
                    "position": {"x": tgt["x"], "y": tgt["y"], "z": tgt["z"]},
                    "velocity": {"x": 0.0, "y": 0.0, "z": 0.0},
                    "acceleration": {"x": 0.0, "y": 0.0, "z": 0.0},
                    "attitude": {"roll": 0.0, "pitch": 0.0, "yaw": tgt["yaw"]},
                    "attitudeRate": {"roll": 0.0, "pitch": 0.0, "yaw": 0.0},
                    "thrust": 0.0,
                }
                state = {
                    "position": {"x": p[0], "y": p[1], "z": p[2]},
                    "velocity": {"x": v[0], "y": v[1], "z": v[2]},
                    "attitudeQuaternion": {"x": q[0], "y": q[1], "z": q[2], "w": q[3]},
                    "attitude": {"yaw": mel.degrees(rpy[2])},
                }
                # The reference reads body rates off the IMU. We get no telemetry back
                # over ESP-NOW, so they come from the mocap attitude derivative instead
                # -- same quantity, ~25 Hz instead of 500, which is why the kw_* and
                # kd_omega_rp gains want turning DOWN from the reference values.
                sensors = {"gyro": {"x": mel.degrees(w[0]), "y": mel.degrees(w[1]),
                                    "z": mel.degrees(w[2])}}

                ctl, lg = ctrl.update(setpoint, state, sensors, TICK)
                # Straight to the wire: the drone's mixer turns (F_x, F_y, M_z, F_z)
                # into m1..m4 exactly as the reference Sblimp firmware does.
                ser.write(wrench_frame(ctl["roll"], ctl["pitch"], ctl["yaw"], ctl["thrust"]))
                with lock:
                    S["vel"] = [round(x, 3) for x in v]
                    S["gyro"] = [round(mel.degrees(x), 1) for x in w]
                    S["ctl"] = {k: round(val, 2) for k, val in ctl.items()}
                    S["log"] = {k: round(val, 4) for k, val in lg.items()}
                    # what went on the wire; per-motor values come back via "telem"
                    S["wrench"] = [round(ctl["roll"], 1), round(ctl["pitch"], 1),
                                   round(ctl["yaw"], 1), round(ctl["thrust"], 1)]
            else:
                was_engaged = False
                ser.write(ZERO_FRAME)
                with lock: S["wrench"] = [0.0] * 4
        except Exception as e:
            with lock: S["err"] = "bridge write: %s" % e; S["armed"] = False
        time.sleep(TICK)


# -------------------------------------------------------------------- HTTP --
def state_payload():
    p, q, valid, _t = pose()
    rpy = mel.quat2rpy(q)
    with lock:
        return {
            "valid": valid, "rate": S["rate"],
            "pos": [round(v, 3) for v in p],
            "rpy": [round(mel.degrees(v), 1) for v in rpy],
            "vel": list(S["vel"]), "gyro": list(S["gyro"]),
            "armed": S["armed"], "engaged": S["engaged"], "bridge": S["bridge"],
            "err": S["err"], "target": dict(S["target"]),
            "gains": dict(S["gains"]), "mix": dict(S["mix"]), "layout": S["layout"],
            "motor_enable": list(S["motor_enable"]),
            "motor_map": list(S["motor_map"]),
            "wrench": list(S["wrench"]), "ctl": dict(S["ctl"]), "log": dict(S["log"]),
            "mixinfo": dict(S["mixinfo"]), "alloc": list(S["alloc"]), "auth": list(S["auth"]),
            "bench": S["bench"], "up_axis": S["up_axis"],
            "telem": list(S["telem"]), "telem_age": S["telem_age"],
            "mel_spec": mel.MEL_SPEC, "mix_spec": mel.MIX_SPEC,
            "layouts": list(mel.CANT_LAYOUTS.keys()),
        }


def handle(d):
    a = d.get("action")
    with lock:
        if a == "arm":
            S["armed"] = bool(d.get("on", not S["armed"]))
            if not S["armed"]:
                S["engaged"] = False; S["bench"] = None
        elif a == "engage":
            on = bool(d.get("on", not S["engaged"]))
            if on and not S["raw"]["valid"]:
                S["err"] = "engage refused: no mocap tracking"
            else:
                S["engaged"] = on; S["bench"] = None
                if on: S["armed"] = True
        elif a == "kill":
            S["engaged"] = False; S["armed"] = False; S["bench"] = None
        elif a == "gain":
            k = d.get("name")
            if k in mel.MEL_LIMITS:
                lo, hi = mel.MEL_LIMITS[k]
                try: S["gains"][k] = _clamp(float(d.get("value")), lo, hi)
                except Exception: pass
        elif a == "mix":
            k = d.get("name")
            if k in mel.MIX_LIMITS:
                lo, hi = mel.MIX_LIMITS[k]
                try: S["mix"][k] = _clamp(float(d.get("value")), lo, hi)
                except Exception: pass
        elif a == "layout":
            if d.get("value") in mel.CANT_LAYOUTS:
                S["layout"] = d["value"]
        elif a == "motor_enable":
            try:
                i = int(d.get("index"))
                if 0 <= i < 4: S["motor_enable"][i] = 0 if S["motor_enable"][i] else 1
            except Exception: pass
        elif a == "motor_map":
            # Assign a firmware channel to an arm position, SWAPPING with whichever
            # position currently holds that channel. Swapping (rather than plain
            # assignment) keeps the map a valid permutation at every step, so the
            # panel can never leave two positions on one channel and one motor dead.
            try:
                pos = int(d.get("index")); ch = int(d.get("channel"))
            except Exception:
                pos = ch = -1
            if 0 <= pos < 4 and 0 <= ch < 4:
                cur = S["motor_map"].index(ch)
                S["motor_map"][cur] = S["motor_map"][pos]
                S["motor_map"][pos] = ch
        elif a == "reset_map":
            S["motor_map"] = [0, 1, 2, 3]
        elif a == "target":
            for k in ("x", "y", "z", "yaw"):
                if k in d:
                    try: S["target"][k] = float(d[k])
                    except Exception: pass
        elif a == "target_here":
            px = _map_raw(dict(S["raw"]), S["up_axis"])
            S["target"]["x"], S["target"]["y"] = round(px[0], 3), round(px[1], 3)
        elif a == "bench":
            # PROPS OFF. Spins one channel so you can map M1..M4 to physical motors.
            i = d.get("index")
            S["bench"] = None if i is None else (int(i), float(d.get("duty", 0.15)))
            if S["bench"] is not None:
                S["engaged"] = False; S["armed"] = True
        elif a == "reset_gains":
            S["gains"] = dict(mel.MEL_DEFAULTS)
        elif a == "reset_mix":
            S["mix"] = dict(mel.MIX_DEFAULTS)
        elif a == "up_axis":
            if d.get("value") in ("Y", "Z"): S["up_axis"] = d["value"]
        elif a == "clear_err":
            S["err"] = ""
    if a == "save":
        save_cfg()
        with lock: S["err"] = "saved %s" % os.path.basename(CFG)
    return {"ok": True}
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

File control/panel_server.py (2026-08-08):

#!/usr/bin/env python3
"""
panel_server.py — ON-BOARD autonomous flight panel for the ESP-FLY blimp.

Serves three pages from one server, chosen at launch:
  (default)   auto_panel.html    autonomous flying + live tuning
  --manual    manual_panel.html  hand-fly only
  --wander    wander_panel.html  fly to a point, park, wait for a hand push, repeat

The DRONE does ALL the control math (firmware blimp_guidance.c: path-following +
carrot + arrival hold + hover). This Mac panel ONLY:
  1. reads the mocap (NatNet) for the blimp,
  2. STREAMS the pose + target to the drone (0xA6 frames), and
  3. streams the tuning gains (0xA7 frames) when you move a slider.
Nothing about the trajectory is computed here — the sliders just retune the
loops running on the drone, live, with no reflash.

  OptiTrack --lab WiFi--> Mac (this panel) --USB--> C6 --ESP-NOW--> blimp (S3)

One tracked rigid body (--body, the blimp). The target is set in the panel:
a drawn path, a circle, or the manual Target X/Y/Z boxes.

HOW ENGAGE / DISENGAGE WORKS (one-way ESP-NOW): the drone auto-engages the
on-board controller the instant it receives a pose frame, and its own
mocap-stale failsafe (blimpc.staleMs) stops the motors if the frames stop.
So GO = start streaming pose; STOP = stop streaming pose (the panel also sends
a few zero manual frames, which drop the drone's autonomous latch immediately).

The path/carrot drawn in the panel is a LOCAL MIRROR of the on-board math, for
visualization only — the real numbers live on the drone (CRTP log group blimpc).

Run it with `python run.py` from the repo root, or directly:
  python panel_server.py --server 192.168.0.4 --body 531
then open http://127.0.0.1:8601
"""
import argparse, glob, json, math, os, struct, subprocess, sys, threading, time, webbrowser
from http.server import BaseHTTPRequestHandler, ThreadingHTTPServer


def find_bridge_port():
    """Auto-detect the XIAO C6 bridge serial port on macOS / Windows / Linux."""
    try:  # pyserial's cross-platform enumerator (works on Windows COM ports)
        from serial.tools import list_ports
        ports = list(list_ports.comports())
        for p in ports:  # prefer obvious USB-serial / ESP adapters
            blob = ((p.description or "") + (p.manufacturer or "") +
                    (p.device or "")).lower()
            if any(s in blob for s in ("usbmodem", "wchusbserial", "cp210",
                                       "ch340", "esp", "uart", "silicon", "wch")):
                return p.device
        if ports:
            return ports[0].device
    except Exception:
        pass
    g = (glob.glob("/dev/cu.usbmodem*") + glob.glob("/dev/cu.wchusbserial*") +
         glob.glob("/dev/ttyUSB*") + glob.glob("/dev/ttyACM*"))
    return g[0] if g else ""

DIR = os.path.dirname(os.path.abspath(__file__))
PORT = 8601
TICK = 0.05                # 50 ms = 20 Hz pose stream (gentler on the ESP-NOW link)
FULL = 65535               # forward motor full duty (manual test path)
PITCH_MAX = 32767          # int16 cap on the vertical/turn setpoint channels
M_VERT_SIGN = -1.0         # up/down hardware orientation (manual test path)
M_FWD_RAMP = 0.05          # per-tick fwd_level ramp (hold-W)
HOVER_UP_FRAC = 0.6        # hover baseline = this fraction of the Up power slider
AXES_STALE_S = 0.4         # gamepad input older than this is ignored (pad unplugged
                           # / tab backgrounded -> fall back to keys, never latch on)
Z_HOLD_KP = 0.9            # open-loop-test altitude hold: up-fraction per metre of error
Z_HOLD_CAP = 0.20          # ...max EXTRA lift above hover baseline (caps climb -> no ceiling)
Z_PROBE_TARGET = 1.5       # altitude (m) the open-loop probes auto-hold at
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

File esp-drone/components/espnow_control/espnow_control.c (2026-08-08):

/*
 * espnow_control.c — ESP-NOW receiver for the ESP-FLY blimp.
 * See espnow_control.h for the protocol and design rationale.
 */
#include <string.h>
#include <math.h>

#include "freertos/FreeRTOS.h"
#include "freertos/task.h"
#include "esp_log.h"
#include "esp_wifi.h"
#include "esp_event.h"
#include "esp_netif.h"
#include "esp_now.h"

#include "espnow_control.h"

#define TAG "ESPNOW_CTRL"
#define ESPNOW_CHANNEL 1        /* must match the C6 bridge's ESPNOW_CHANNEL */
#define FAILSAFE_MS 250         /* no packet this long -> zero the motors (was 400;
                                 * tightened -- this is only a BACKSTOP for total
                                 * ESP-NOW loss now, since blimp_guidance's own
                                 * mocap-staleness check (bc_staleMs, default 300ms)
                                 * fires first and faster whenever pose frames stop,
                                 * even if manual/gain frames are still arriving) */

static espnow_setpoint_cb_t s_cb = NULL;
static espnow_mocap_cb_t s_mocap_cb = NULL;
static espnow_gains_cb_t s_gains_cb = NULL;
static espnow_failsafe_cb_t s_fail_cb = NULL;
static volatile uint32_t s_last_ms = 0;
static volatile bool s_active = false;

static inline uint32_t now_ms(void)
{
    return (uint32_t)(xTaskGetTickCount() * portTICK_PERIOD_MS);
}

/* ============================================================================
 * FRAME_MAGIC -- unique ID for THIS drone/bridge pair. Every one of OUR frames
 * carries this 4-byte tag as its first bytes; anything without it is ignored.
 * This is what lets multiple ESP-FLY blimps share one room without cross-talk
 * -- give each pair its own value here AND in the matching FRAME_MAGIC in
 * espnow_bridge/espnow_bridge.ino, then reflash both boards. (Also filters
 * out other labs' ESP-NOW traffic, which is why this exists at all -- see
 * espnow_bridge/README.md, "Multiple drones in the same room".)
 * ============================================================================ */
static const uint8_t FRAME_MAGIC[4] = { 0xB1, 0x12, 0x9F, 0x5A };

/* TELEMETRY tag (drone -> bridge -> Mac). Distinct from FRAME_MAGIC so the bridge
 * and any listeners can tell our motor-telemetry frames apart from control frames. */
static const uint8_t TELEM_MAGIC[4] = { 0xB7, 0x1E, 0x30, 0xA5 };
static const uint8_t BCAST_ADDR[6] = { 0xFF, 0xFF, 0xFF, 0xFF, 0xFF, 0xFF };
static bool s_bcast_ready = false;

static volatile float s_telem_motors[4] = {0, 0, 0, 0};  /* last motor cmds (cached) */

/* Broadcast the cached 4 motor values (TELEM_MAGIC + 16 bytes). Called both from
 * the guidance loop (fresh values) and the failsafe task (heartbeat), so the Mac
 * ALWAYS gets a telemetry stream -- zeros when idle, real commands in flight --
 * which makes the drone->bridge->Mac link verifiable on the bench (motors off). */
static esp_err_t send_telem_now(void)
{
    if (!s_bcast_ready) return ESP_ERR_INVALID_STATE;
    uint8_t buf[4 + 16];
    memcpy(buf, TELEM_MAGIC, 4);
    memcpy(buf + 4, (const void *)s_telem_motors, 16);  /* 4 LE float32: fwdL,fwdR,up,down */
    return esp_now_send(BCAST_ADDR, buf, sizeof(buf));
}

void espnowControlSendTelem(const float motors4[4])
{
    s_telem_motors[0] = motors4[0]; s_telem_motors[1] = motors4[1];
    s_telem_motors[2] = motors4[2]; s_telem_motors[3] = motors4[3];
    send_telem_now();
}

static void recv_cb(const esp_now_recv_info_t *info, const uint8_t *data, int len)
{
    /* Reject any frame that is not ours (no magic tag). Room has MANY drones on
     * ESP-NOW; log rejected foreign traffic occasionally so it stays visible. */
    if (len < 4 || memcmp(data, FRAME_MAGIC, 4) != 0) {
        static uint32_t rxForeign = 0;
        if ((rxForeign++ % 200) == 0) {
            const uint8_t *m = info->src_addr;
            ESP_LOGI(TAG, "ignored FOREIGN rx from %02x:%02x:%02x:%02x:%02x:%02x len=%d (no magic)",
                     m[0], m[1], m[2], m[3], m[4], m[5], len);
        }
        return;
    }
    /* strip the 4-byte magic: dispatch on the real payload only */
    data += 4;
    len  -= 4;

    /* 92-byte payload = live GAIN tuning (23 float32, matches BLIMP_NUM_GAINS).
     * Checked first; never drives motors, just updates gains. Validated by the
     * handler. */
    if (len >= 92 && s_gains_cb) {
        float g[23];
        memcpy(g, data, sizeof(g));
        s_gains_cb(g);
        ESP_LOGI(TAG, "gains rx (kpZ=%.0f yawKpHead=%.1f rateMax=%.0f vCruise=%.2f)",
                 g[0], g[5], g[6], g[9]);
        return;
    }
    /* 32-byte payload = AUTONOMOUS mocap pose (8 float32: cx,cy,cz,cyaw,tx,ty,tz,tyaw).
     * Checked before the 16-byte manual case, so it is never mistaken for one.
     * Validated so noise/other devices can't engage autonomy. */
    if (len >= 32 && len < 92 && s_mocap_cb) {
        float p[8];
        memcpy(p, data, sizeof(p));
        for (int i = 0; i < 8; i++) {
            if (!isfinite(p[i])) return;
        }
        /* positions must be within a sane arena (+/-50 m); reject junk */
        if (fabsf(p[0]) > 50.0f || fabsf(p[1]) > 50.0f || fabsf(p[2]) > 50.0f ||
            fabsf(p[4]) > 50.0f || fabsf(p[5]) > 50.0f || fabsf(p[6]) > 50.0f) {
            return;
        }
        s_mocap_cb(p);
        s_last_ms = now_ms();
        s_active = true;
        static uint32_t m = 0;
        if ((m++ % 50) == 0) {
            ESP_LOGI(TAG, "mocap rx #%u pos=(%.2f,%.2f,%.2f) tgt=(%.2f,%.2f,%.2f)",
                     (unsigned)m, p[0], p[1], p[2], p[4], p[5], p[6]);
        }
        return;
    }
    if (len >= 16 && s_cb) {
        float v[4];
        memcpy(v, data, sizeof(v));        /* roll, pitch, yaw, thrust (LE float32) */
        /* Reject stray/garbage ESP-NOW frames (other devices, noise): the values
         * must be finite and in a sane setpoint range, or motors would spin on junk. */
        if (!isfinite(v[0]) || !isfinite(v[1]) || !isfinite(v[2]) || !isfinite(v[3]) ||
            fabsf(v[1]) > 40000.0f || fabsf(v[2]) > 40000.0f ||
            v[3] < -1.0f || v[3] > 70000.0f) {
            return;
        }
        s_cb(v[0], v[1], v[2], v[3]);
        s_last_ms = now_ms();
        s_active = true;
        static uint32_t n = 0;             /* link-confirm: log every ~50th frame */
        if ((n++ % 50) == 0) {
            ESP_LOGI(TAG, "rx #%u pitch=%.0f yaw=%.0f thr=%.0f",
                     (unsigned)n, v[1], v[2], v[3]);
        }
    }
}
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

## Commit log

2026-08-08 ESP-FLY autonomous blimp: firmware, ESP-NOW bridge, flight panels, and hardware
    [balloon-mount-v2.stl, blimp-gondola-mount.f3d, esp-blimp-frame.f3d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]
2026-08-08 Replace macOS .command launchers with a cross-platform flash.py
    [panel_server.py]
2026-08-08 Gamepad in manual mode; drop the goal marker and LED bench test; bridge works on S3 or C6
2026-08-08 Clarify the handover notes cover the standard 2-forward-motor blimp
